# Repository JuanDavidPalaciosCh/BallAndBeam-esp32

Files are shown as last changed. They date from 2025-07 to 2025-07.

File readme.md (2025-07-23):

# 🎯 Proyecto Ball and Beam con PID y ESP32

Este proyecto implementa un sistema **Ball and Beam** controlado mediante un **controlador PID**, calculado y ajustado desde una interfaz gráfica hecha con **Streamlit**, y ejecutado en una **ESP32** que maneja sensores láser y un servomotor.

---
## 🎥 Video de demostración

Video de demostración del proyecto funcional

[Video Demostración Ball and Beam](https://youtu.be/OQszjQ7q160)

---

## 📌 Descripción de la planta

La planta utilizada corresponde al modelo clásico de Ball and Beam descrito en la Universidad de Michigan:  
[https://ctms.engin.umich.edu/CTMS/index.php?example=BallBeam&section=SystemModeling](https://ctms.engin.umich.edu/CTMS/index.php?example=BallBeam&section=SystemModeling)

Se modela como:

\[
P(s) = \frac{k}{s^2}
\]

donde:
- **m** = 0.021 kg (masa de la bola),
- **g** = 9.81 m/s² (gravedad),
- **d** = 0.05 m (distancia eje-haz),
- **L** = 0.4 m (longitud del haz),
- **J** = 9.99e-6 kg·m² (momento de inercia de la bola),
- **Radio** = 0.03 m (radio de la bola).

---

## ⚡ Hardware

### 🔩 Servomotor
- **Modelo:** MG996R 11Kg (4.8 V) Piñonería metálica.
- **Pin de control:** GPIO 18 de la ESP32.
- **GND del servo:** debe ir al mismo GND de la ESP32.

### 📡 Sensores láser
Se utilizan dos sensores **VL53L0X** conectados por I2C:
- **SDA:** GPIO 21 (estándar I2C)
- **SCL:** GPIO 22 (estándar I2C)
- **XSHUT1:** GPIO 23
- **XSHUT2:** GPIO 19  
Estos pines XSHUT permiten inicializar cada sensor con una dirección I2C distinta.

---

## 🖥️ Software

El proyecto se compone de los siguientes directorios y archivos:

### 🤖 Código para la ESP32

- [`controlpid/controlpid.ino`](controlpid/controlpid.ino):  
  Código cargado en la ESP32.  
  - Inicializa los dos sensores VL53L0X por I2C (SDA=21, SCL=22, XSHUT en pines 19 y 23).
  - Controla el servomotor MG996R por el pin 18.
  - Ejecuta el PID con parámetros enviados por WiFi desde la aplicación.

- [`controlpid/prueba_wifi/prueba_wifi.ino`](controlpid/prueba_wifi/prueba_wifi.ino):  
  Código de prueba para conectarse al WiFi y obtener la IP de la ESP32.  
  ⚠️ Usa este código para averiguar la IP que debes configurar en la app Streamlit 
  (main.py).

---

### 📒 Simulación teórica

- [`cont_teorico/teorico.ipynb`](cont_teorico/teorico.ipynb):  
  Aquí se desarrolla la simulación teórica de la planta y se calculan los valores iniciales del PID:

```python
alpha = k
n = 3

wn = 0.799
zeta = 0.95

kp = (wn**2 * (2*zeta*n + 1)) / alpha
ki = (n*wn**3) / alpha
kd = (wn*(2*zeta+n))/ alpha
```

✅ Valores iniciales calculados:

    Kp = -5.33

    Ki = -1.91

    Kd = -4.88

    Ts = 0.2

🖼️ Resultados de la simulación:

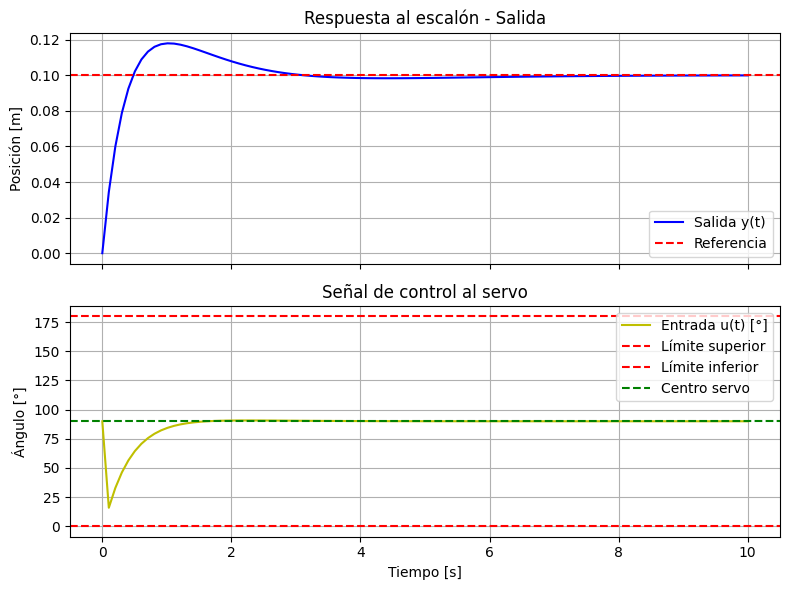
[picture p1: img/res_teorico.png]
Imagen resultados


--- 

🌐 Aplicación Streamlit

Imagen de la app:

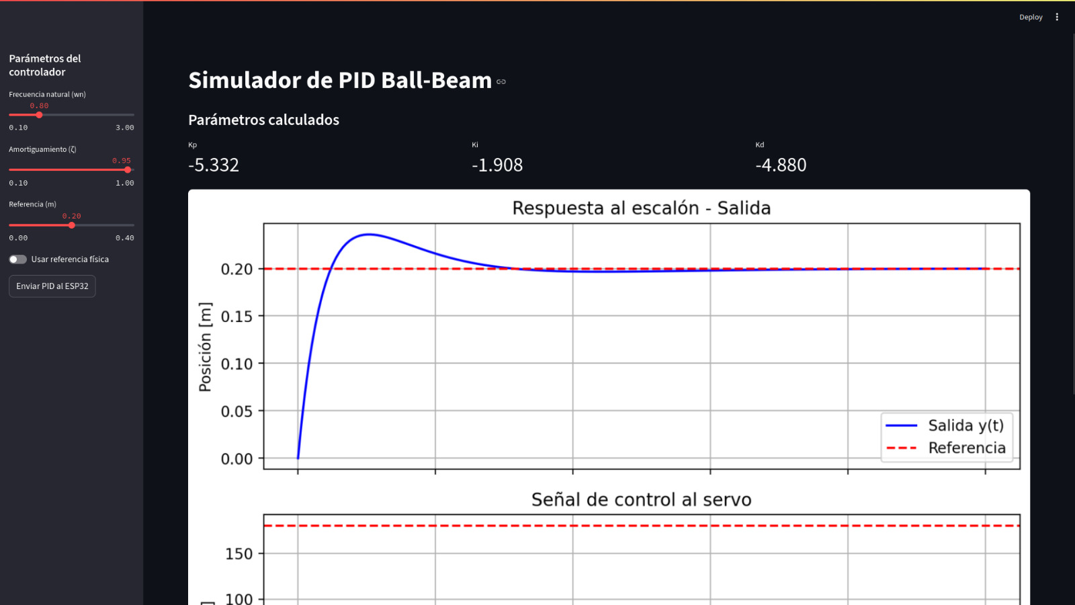
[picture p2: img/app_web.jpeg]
Imagen App


streamlit_app/main.py

    Interfaz gráfica principal.

    Permite ingresar parámetros de diseño y ver la simulación.

    Envía los valores de Kp, Ki, Kd y la referencia a la ESP32 usando la IP obtenida con prueba_wifi.ino.

streamlit_app/controlador.py

    Función calcular_pid_y_simular:

        Define la planta.

        Calcula Kp, Ki y Kd.

        Simula respuesta al escalón y genera u_deg (señal para el servo).

streamlit_app/enviar_esp.py

    Función enviar_pid_wifi:

        Envía parámetros al ESP32 mediante una petición HTTP GET.

        Uso ejemplo en main.py:

        ok, mensaje = enviar_pid_wifi(kp, ki, kd, dist, ip_esp32="192.168.1.50")

▶️ Cómo ejecutar la app Streamlit

    Ejecuta Streamlit:

```bash streamlit run streamlit_app/main.py```

    En la interfaz, ajusta los parámetros y presiona el botón Enviar PID al ESP32.
    Antes de enviar, asegúrate de haber cargado controlpid.ino en la ESP32 y de haber configurado la IP correcta que obtuviste con prueba_wifi.ino.

---

▶️ Cómo ejecutar el proyecto en fisico

    Sube el codigo *controlpid.ino* a la esp32

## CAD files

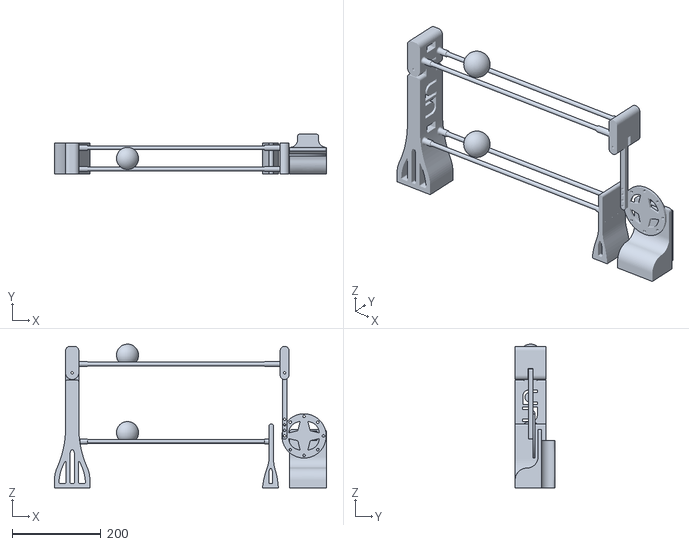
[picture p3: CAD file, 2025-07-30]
Modelocad/BallAndBeamV2.stl
614.7 x 90.0 x 325.0

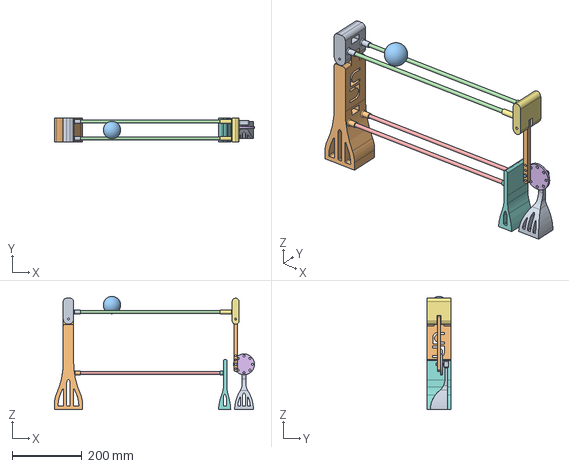
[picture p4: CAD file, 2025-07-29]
Modelocad/BallAndBeam.step
574.0 x 70.0 x 325.0 mm

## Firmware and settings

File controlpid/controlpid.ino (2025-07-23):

#include <ESP32Servo.h>
#include <Wire.h>
#include <Adafruit_VL53L0X.h>
#include <math.h>

// lib wifi
#include <WiFi.h>
#include <WebServer.h>


// ==== PID por defecto ====
float Kp = -4.330;
float Ki =  -1.396;
float Kd =  -4.398;
float Ts = 0.1;
float ref = 0.2;
float distancia1 = 0.2;
float error = 0.0;
int angulo = 90;

int usarReferenciaFisica = 0;

// ==== PID Interno ====
float integral = 0.0;
float error_anterior = 0.0;

// ==== Servo ====
Servo miServo;
int pinServo = 18;

// === Pines XSHUT de cada VL53L0X ===
#define SDA_PIN 21
#define SCL_PIN 22
#define XSHUT1_PIN 23
#define XSHUT2_PIN 19

// ==== Objetos para cada sensor ====
Adafruit_VL53L0X lox1 = Adafruit_VL53L0X();
Adafruit_VL53L0X lox2 = Adafruit_VL53L0X();


// === Variables de filtrado ===
const int N = 5;  // tamaño de ventana
float ref_buffer[N];
int ref_index = 0;
float ref_sum = 0;
int ref_count = 0;


// === Conexion internet ===
// ===== LED indicador =====
const int LED_PIN = 2;

// ===== Servidor HTTP =====
WebServer server(80);

// ===== CONFIGURACIÓN WIFI =====
const char* ssid = "lab_control";
const char* password = "lab_control";

bool serverIniciado = false;


void setup() {
  Serial.begin(115200);
  // WiFi
  startWifi();

  // Servo
  ESP32PWM::allocateTimer(0);
  ESP32PWM::allocateTimer(1);
  ESP32PWM::allocateTimer(2);
  ESP32PWM::allocateTimer(3);
  miServo.setPeriodHertz(50);
  miServo.attach(pinServo, 500, 2400);
  miServo.write(90);

  // I2C
  Wire.begin(SDA_PIN, SCL_PIN);

  inicializarSensoresLaser();

}

void loop() {
  // ===== WiFi ====
  // Verificar conexión WiFi
  if (WiFi.status() == WL_CONNECTED) {
    digitalWrite(LED_PIN, HIGH);
    // Si antes no estaba iniciado el servidor, iniciarlo ahora
    if (!serverIniciado) {
      server.on("/update", handleUpdate);
      server.on("/datos", handleDatos);
      server.begin();
      Serial.println("Servidor HTTP iniciado (loop).");
      serverIniciado = true;
    }
  } else {
    digitalWrite(LED_PIN, LOW);
    serverIniciado = false;
  }

  // Atender peticiones HTTP entrantes
  if (serverIniciado){
    server.handleClient();
  }

  
  // ===== Lecturas =====
  distancia1 = leerSensor(lox1);

  if (distancia1 < 0){
    distancia1 = 0;
  }

  if(WiFi.status() != WL_CONNECTED || usarReferenciaFisica){
    float distancia2 = leerSensor(lox2);
    ref = distancia2 + 0.01;

    if (ref < 0){
      ref = 0;
    }
  }

  // ===== Calcular error =====
  error = ref - distancia1;

  // ===== Zona muerta =====
  if (fabs(error) < 0.001) {
    error = 0;
  }

  // ====== PID ======
  float proporcional = Kp * error;
  float integral_provisional = integral + error * Ki * Ts;
  float derivativo = Kd * (error - error_anterior) / Ts;

  float control_rad = (proporcional + integral_provisional + derivativo);

  Serial.println(control_rad);


  float control_deg = -1* control_rad * 180.0f / (float)M_PI;

  control_deg = constrain(control_deg, -90, 90);

  // ====== Normalizar y saturar ======
  angulo = control_deg + 90;
  

  miServo.write((int)angulo);
  error_anterior = error;

  // ===== Monitor =====
  Serial.print(distancia1, 3);
  Serial.print('\t');        // tabulación
  Serial.print(ref, 3);
  Serial.print('\t');
  //Serial.println(angulo, 1); // última con salto de línea


  delay((int)(Ts * 1000));
}




// === Funciones ===


// ==== Función para leer sensor láser ====
float leerSensor(Adafruit_VL53L0X &lox) {
  VL53L0X_RangingMeasurementData_t measure;
  lox.rangingTest(&measure, false);

  //Serial.println(measure.RangeStatus);
  if (measure.RangeStatus != 4) {
    return 0.45 - ((measure.RangeMilliMeter) / 1000.0);
  }
  return 0.0;
}


// === Funcion para inicializar sensores laser ===
void inicializarSensoresLaser() {
  // Pines XSHUT
  pinMode(XSHUT1_PIN, OUTPUT);
  pinMode(XSHUT2_PIN, OUTPUT);

  // Apagar ambos sensores
  digitalWrite(XSHUT1_PIN, LOW);
  digitalWrite(XSHUT2_PIN, LOW);
  delay(1000);

  // Inicializar sensor 1
  digitalWrite(XSHUT1_PIN, HIGH);
  delay(1000);
  if (!lox1.begin(0x30)) {
    Serial.println(F("¡Fallo sensor 1!"));
    while (1);
  }
  Serial.println(F("Sensor 1 listo"));

  delay(500);

  // Inicializar sensor 2
  digitalWrite(XSHUT2_PIN, HIGH);
  delay(100);
  if (!lox2.begin(0x31)) {
    Serial.println(F("¡Fallo sensor 2!"));
    while (1);
  }
  Serial.println(F("Sensor 2 listo"));
  delay(1000);
}

// === Funciones wifi ===
// ===== HANDLER para actualizar PID =====
void handleUpdate() {
  // Leer parámetros de la URL si existen
  if (server.hasArg("kp")) Kp = server.arg("kp").toFloat();
  if (server.hasArg("ki")) Ki = server.arg("ki").toFloat();
  if (server.hasArg("kd")) Kd = server.arg("kd").toFloat();

  if (server.hasArg("ref_fisica")) {
    usarReferenciaFisica = (server.arg("ref_fisica") == "1");
  }
  
  // Solo actualizar ref si NO estamos usando referencia física
  if (!usarReferenciaFisica && server.hasArg("dist")) {
    ref = server.arg("dist").toFloat();
  }

  String message = "Valores PID actualizados:\n";
  message += "Kp = " + String(Kp, 4) + "\n";
  message += "Ki = " + String(Ki, 4) + "\n";
  message += "Kd = " + String(Kd, 4) + "\n";
  message += "Ref = " + String(ref, 4) + "\n";
  message += "RefFisica = " + String(usarReferenciaFisica ? "Sí" : "No") + "\n";

  server.send(200, "text/plain", message);
  Serial.println(message);
}


// === HANDLER para mandar datos ===
void handleDatos() {
  String json = "{";
  json += "\"distancia\":" + String(distancia1, 3) + ",";
  json += "\"ref\":" + String(ref, 3) + ",";
  json += "\"error\":" + String(error, 3) + ",";
  json += "\"angulo\":" + String(angulo, 1);
  json += "}";
  server.send(200, "application/json", json);
}


void startWifi() {
  delay(1000);
  
  pinMode(LED_PIN, OUTPUT);
  digitalWrite(LED_PIN, LOW); // LED apagado inicialmente
  
  Serial.println("Conectando a WiFi...");
  WiFi.begin(ssid, password);
  
  // Tiempo máximo de espera en milisegundos
  unsigned long tiempoInicio = millis();
  unsigned long tiempoEspera = 5000; // 5 segundos
  
  while (WiFi.status() != WL_CONNECTED && (millis() - tiempoInicio) < tiempoEspera) {
    delay(500);
    Serial.print(".");
  }
  
  if (WiFi.status() == WL_CONNECTED) {
    Serial.println("");
    Serial.println("WiFi conectado.");
    Serial.print("IP asignada: ");
    Serial.println(WiFi.localIP());
    digitalWrite(LED_PIN, HIGH); // LED encendido
    // Configurar rutas del servidor
    server.on("/update", handleUpdate);
    server.on("/datos", handleDatos);
    
    server.begin();
    serverIniciado = true;
    Serial.println("Servidor HTTP iniciado.");
  } else {
    Serial.println("");
    Serial.println("⚠️ No se pudo conectar al WiFi en el tiempo esperado. Continuando...");
  }
  
}

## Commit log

2025-07-21 Fix PID controller
2025-07-23 wifi implemented, fixed bugs on pid controller
    [controlpid.ino, prueba_wifi.ino]
2025-07-29 Se agrega modelo cad
    [BallAndBeam.step]
2025-07-30 Added second version of cad model
    [BallAndBeamV2.stl]
